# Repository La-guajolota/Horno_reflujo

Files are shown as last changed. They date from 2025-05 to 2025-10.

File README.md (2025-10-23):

<!-- @format -->

# 🔥 Homemade SMD Reflow Oven 🔥

<p align="center">
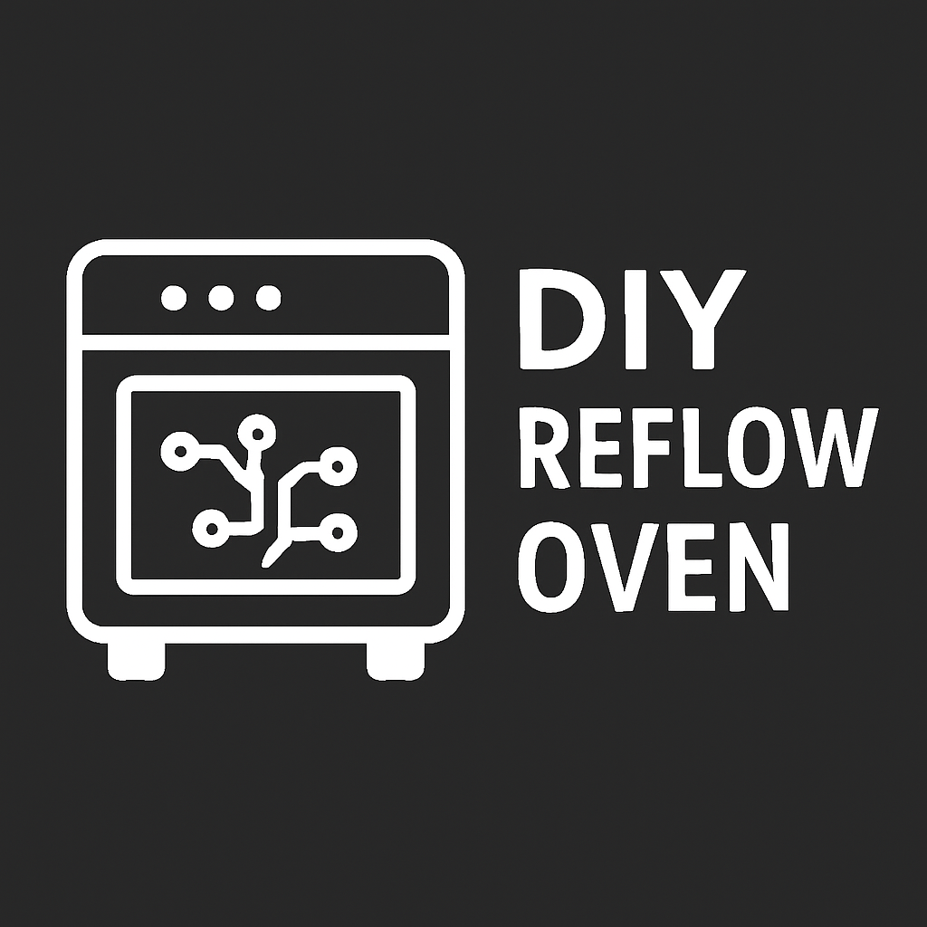
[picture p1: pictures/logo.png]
Project Logo
    
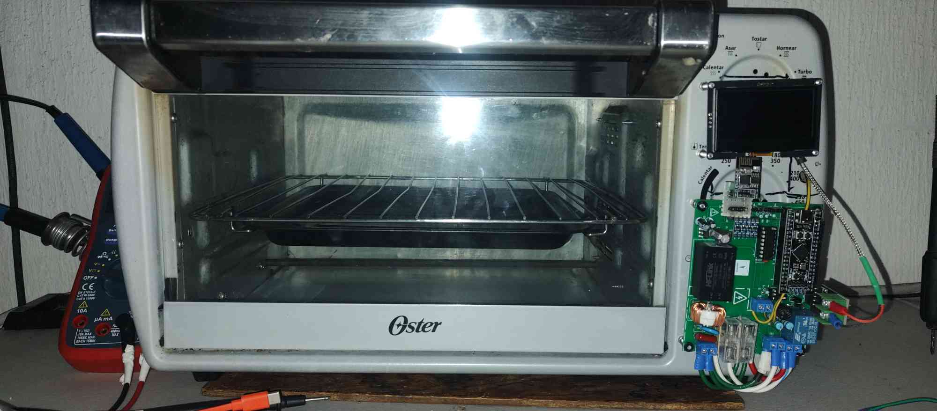
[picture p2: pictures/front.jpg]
Oven
    
</p>

## 📑 Table of Contents

- [Overview](#-overview)
- [Project Demo](#-project-demo)
- [Workflow](#-workflow)
- [Technical Challenges](#-technical-challenges)
- [Repository Structure](#-repository-structure)
- [Requirements & Dependencies](#-requirements--dependencies)
- [Installation & Usage](#-installation--usage)
- [To-Do List](#-to-do-list)
- [Possible Improvements](#-possible-improvements)
- [Safety Considerations](#-safety-considerations)
- [Contributing](#-contributing)
- [Reference Links](#-reference-links)
- [License](#-license)

---

## 📝 Overview

The **SMD Reflow Oven** is an open-source project designed for precise SMD soldering. It utilizes configurable thermal profiles managed by an **STM32F411** microcontroller and a web-based GUI hosted on an **ESP01-S**. Key features include real-time PID temperature control, smart power management, and robust safety systems.

> ✅ **Functional Demo**: All core features (PID control, temperature sensing, web GUI, and the reflow algorithm) are fully operational and ready for soldering SMD components.
> 🚧 **Active Development**: Both the firmware and hardware are under continuous improvement.

---

## 📹 Project Demo

See the oven in action! This video demonstrates its current functionality and soldering capabilities.

<p align="center">
<a href="https://youtu.be/XSk6v5LdElc?si=d4BS0npnXu5F3Sj0" target="_blank">
<b>Watch a video demonstration of the oven in action</b>
</a>
</p>

---

## 🔄 Workflow

<details>
<summary><b>Step-by-step SMD soldering process</b></summary>

### 1. 📋 PCB Preparation

- Apply solder paste evenly using a stencil.
- Carefully place the SMD components onto the pasted pads.

<p align="center">
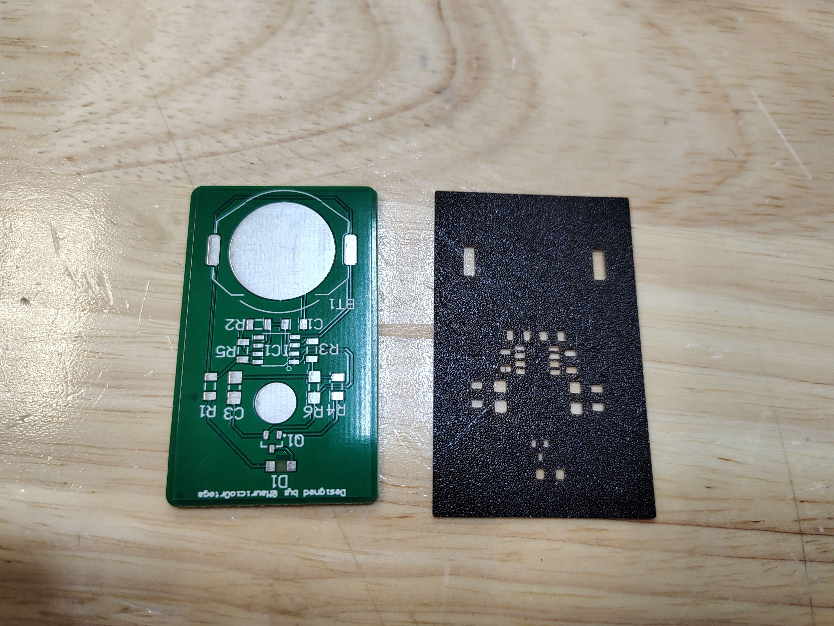
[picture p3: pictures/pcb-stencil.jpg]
PCB Preparation Example

</p>

### 2. ⚙️ Oven Setup

- Power the oven (120V AC).
- Select the appropriate thermal profile for your solder type via the web GUI.
- Verify that all safety systems are active.

### 3. 🔥 Soldering Process

- Place the prepared PCB inside the oven chamber.
- Close the door securely and start the process from the interface.
- Monitor the temperature curve in real-time to ensure it follows the selected profile.

<p align="center">
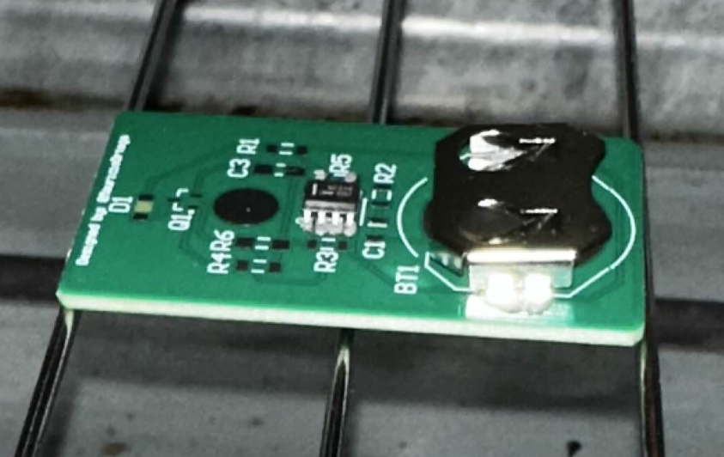
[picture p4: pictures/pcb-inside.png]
PCB Inside Oven

</p>

### 4. 🔍 Final Inspection

- Wait for the **Cooldown** phase to complete before opening the door.
- Allow the PCB to cool completely before handling.
- Inspect the solder joints with a magnifier or microscope for any defects.
- Perform electrical tests to check for shorts or open circuits.

<p align="center">
<a href="https://youtube.com/shorts/ztY0c23UdZQ?si=FxfqCBQ48sNtS6zn" target="_blank">
📺 Watch the final results on YouTube
</a>
</p>
</details>

---

## 🎯 Technical Challenges

| Challenge | Solution Approach |
| :--- | :--- |
| **Temperature Control** | Ensure uniform heat distribution, implement adaptable thermal curves, and design profiles to prevent component microcracks. |
| **Risk Management** | Implement automatic overheating detection and shutoff, along with a system for filtering potentially toxic vapors. |
| **Operational Precision** | Calibrate sensors accurately and synchronize heating/cooling stages for reliable and repeatable results. |

---

## 📂 Repository Structure

The **Serial Peripheral Interface (SPI)** is crucial in this project for fast communication between the STM32 microcontroller and peripherals like the **MAX6675 thermocouple sensors**, ensuring precise, real-time temperature readings for the PID control loop.

```
.
├── Firmware/                   # Firmware for all microcontrollers
│   ├── esp01/                  # ESP-01S firmware and related tools
│   ├── nextionGUI/             # Nextion HMI screen GUI files
│   └── stm32f411/              # STM32F411 firmware and related tools
├── Hardware/                   # Hardware design files (schematics, PCB)
│   ├── horno_no_modificado/  # Original, unmodified oven schematics
│   └── horno_reflujo/        # Custom reflow oven hardware
├── pictures/                   # Project images and photos
├── .gitignore                  # Git ignore file
├── LICENSE                     # Project license
└── README.md                   # This README file
```

---

## 📦 Requirements & Dependencies

### Software

- **PlatformIO**: Recommended for firmware development.
- **Python 3.x**: For data analysis and utility scripts.
- **KiCad**: For viewing and editing hardware schematics and PCB layouts.
- **STM32CubeIDE**: Optional, for STM32-specific development.

### Hardware

- Refer to the **Bill of Materials (BOM)** located in the `Hardware/horno_reflujo/` directory for a complete list of components.

---

## 🛠️ Installation & Usage

1.  **Clone the Repository:**
    ```bash
    git clone https://github.com/La-guajolota/Horno_reflujo.git
    cd Horno_reflujo
    ```
2.  **Setup Firmware:**
    - Open the `Firmware/` and `stm32f411/` directories in PlatformIO.
    - Follow the specific setup instructions within each folder to compile and upload the firmware.
3.  **Assemble Hardware:**
    - Use the schematics and PCB files in the `Hardware/` directory as a guide.
    - Solder and assemble all components according to the BOM.
4.  **Calibrate & Test:**
    - Before the first use, perform temperature sensor calibration.
    - Test all safety systems to ensure they are functioning correctly.

---

## 📋 To-Do List

### High Priority

- [ ] Complete the documentation for hardware assembly.
- [ ] Implement a physical emergency stop button.
- [ ] Create a detailed guide for sensor calibration procedures.
- [ ] Add unit tests for critical firmware functions.

### Medium Priority

- [ ] Develop a mobile-friendly interface or a dedicated app.
- [ ] Add data logging and analysis features to track performance.
- [ ] Create 3D printable designs for the enclosure.

### Low Priority

- [ ] Integrate with PCB design software for profile suggestions.
- [ ] Add cloud connectivity for remote monitoring.

---

## 🚀 Possible Improvements

### Firmware Enhancements

- **Advanced PID Control**: Implement auto-tuning algorithms and adaptive control for even greater precision.
- **Enhanced Safety**: Add redundant sensors and fail-safe mechanisms.
- **Intuitive UI**: Improve the user interface with a touchscreen, OLED display, or rotary encoder.
- **IoT Integration**: Allow for remote monitoring and control over the internet.
- **Ventilation Control**: Develop an automated system to manage toxic vapor extraction.

### Hardware Upgrades

- **Improved Insulation**: Enhance thermal efficiency and user safety.
- **High-Accuracy Sensors**: Upgrade to more precise temperature sensors.
- **Modular Design**: Create a modular system to support different oven sizes.
- **Power Efficiency**: Optimize heating element control to reduce energy consumption.
- **Electrical Isolation**: Improve electrical isolation between high-voltage and low-voltage circuits.

---

## ⚠️ Safety Considerations

- ⚡ **High Voltage**: This project involves **120V AC**. Exercise extreme caution and ensure all connections are properly insulated.
- 🌡️ **High Temperatures**: The oven reaches temperatures capable of causing severe burns. Use protective equipment.
- 💨 **Ventilation**: Solder paste fumes can be toxic. Operate the oven in a well-ventilated area.
- 🔧 **Grounding**: Ensure the oven chassis is properly grounded to prevent electrical shock.
- 📏 **Calibration**: Regularly calibrate temperature sensors to maintain accuracy and prevent overheating.

---

## 🤝 Contributing

Contributions are welcome\! If you'd like to help improve this project, please follow these steps:

1.  **Fork the repository.**
2.  Create a new branch: `git checkout -b feature/your-amazing-feature`
3.  Make your changes and commit them: `git commit -m 'Add your amazing feature'`
4.  Push to your branch: `git push origin feature/your-amazing-feature`
5.  **Open a Pull Request** and describe the changes you've made.

Please report any bugs or suggest features by opening an issue on GitHub.

---

## 🔗 Reference Links

- [Nextion HMI Displays](https://nextion.tech/) – Official site for Nextion touchscreen displays.
- [gerber_to_scad (GitHub)](https://github.com/kirberich/gerber_to_scad) – Tool for generating 3D stencils from Gerber files.
- [SMD Soldering Guidelines](https://www.surfacemountprocess.com/reflow-soldering-process.html) – Comprehensive guide to the reflow soldering process.
- [Reflow Soldering Profiles (SMTA)](https://www.smta.org/) – Industry resources and recommended thermal profiles.
- [DIY Reflow Oven on Instructables](https://www.instructables.com/DIY-REFLOW-OVEN/) – Step-by-step guide for building a reflow oven with open-source firmware.
- [Hack Your Toaster Oven to Become a Thermocouple Measurement System (All About Circuits)](https://www.allaboutcircuits.com/projects/hack-your-toaster-oven-to-become-a-thermocouple-measurement-system/) – Reference for thermocouple integration and reflow process insights.
- [Better SPI Bus Design in 3 Steps (DorkbotPDX)](https://dorkbotpdx.org/blog/paul/better_spi_bus_design_in_3_steps/) – Key considerations for reliable MAX6675 sensor communication.

---

## 📄 License

This project is licensed under the **MIT License**. See the [LICENSE](https://www.google.com/search?q=LICENSE) file for more details. This means you are free to use, modify, and distribute the project, provided you include the original copyright and license notice.

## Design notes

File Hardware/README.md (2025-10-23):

# 🛠️ Hardware 🛠️

<p align="center">
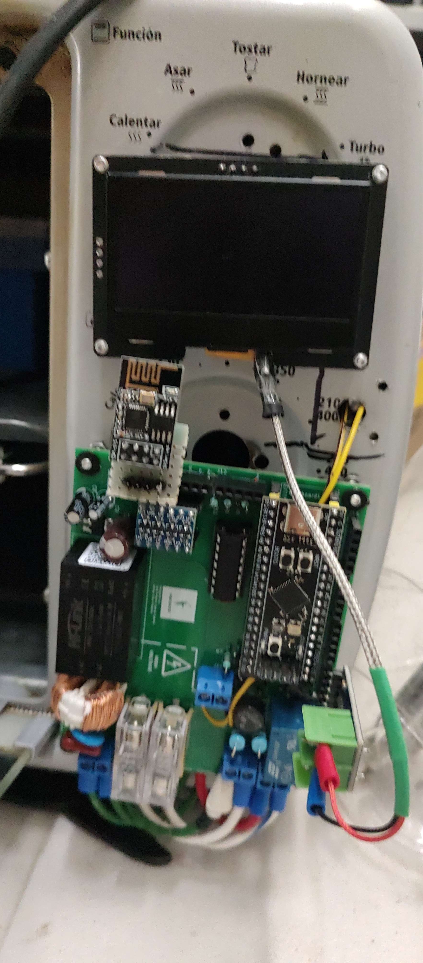
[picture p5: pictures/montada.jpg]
Hardware Banner
  
</p>

This directory contains all the hardware design files for the **SMD Reflow Oven** project. This includes KiCad project files, schematics, PCB layouts, and other related resources.

---

## 📂 Folder Structure

- **horno_no_modificado/**: Contains the original, unmodified schematic files for the oven.
- **horno_reflujo/**: The main KiCad project for the custom reflow oven hardware. This includes:
  -  schematics (`.kicad_sch`)
  - PCB layout (`.kicad_pcb`)
  - Bill of Materials (BOM)
  - Production files for manufacturing.
- **imagenes/**: Reference images and diagrams.

---

## 🚀 Getting Started

To work with the hardware files, you will need:

- **KiCad**: To open and edit the schematic and PCB layout files.

Each subdirectory contains a more detailed `README.md` file with specific instructions on how to use its contents.

---

## 📝 PCB Design Notes & Improvements

While the current electronics are functional, several improvements have been identified for future revisions of the PCB:

- **Component Sizing**: Migrate all through-hole (THT) components to surface-mount (SMD) to reduce board size.
- **Simplify Temperature Sensing**: The current design uses four thermocouples, but one is sufficient. Reducing to a single thermocouple will simplify the circuit and free up microcontroller pins.
- **Isolate Mounting Holes**: The mounting holes are currently connected to the ground plane, which is not ideal. They should be isolated to prevent potential short circuits.
- **Upgrade Connectors**: The external connectors are undersized for the required current. They should be replaced with larger terminals.

---

## 🏠 Enclosure Design Notes & Improvements

The 3D model for the enclosure was designed in Autodesk Inventor. The following improvements have been identified:

- **Reduce Size**: By optimizing the PCB, the enclosure can be made smaller.
- **Improve Closure Mechanism**: The current screw-based closure can be replaced with a more practical solution like snap-fit tabs.
- **Add Accessibility**: Add openings for ventilation and easier access to connectors.

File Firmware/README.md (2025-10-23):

# 펌웨어 | Firmware 펌웨어

<p align="center">
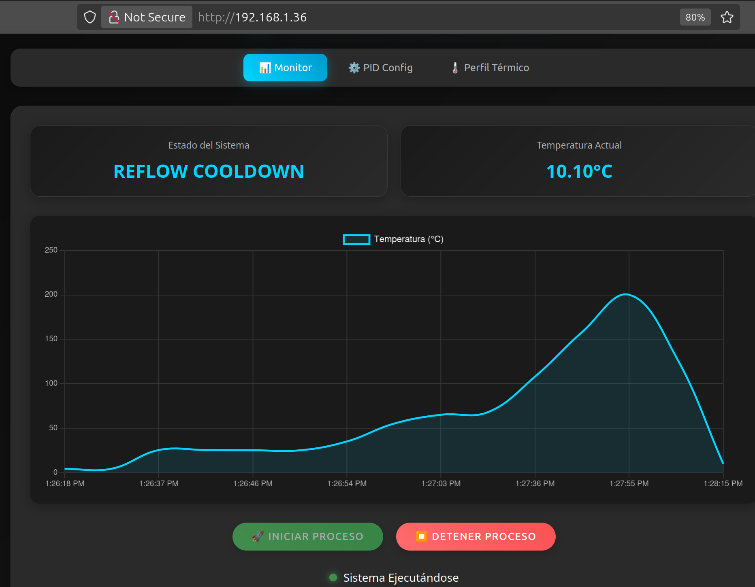
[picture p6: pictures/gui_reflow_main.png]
Firmware Banner
  
</p>

This directory contains all the firmware for the microcontrollers used in the **SMD Reflow Oven** project.

---

## 📂 Subdirectories

Here's a breakdown of what you'll find in each subfolder:

- ###  esp01/
  This folder holds the firmware for the **ESP-01S** module, which is responsible for hosting the web-based GUI. It includes the PlatformIO project and related tools for debugging and data analysis.

- ### nextionGUI/
  Contains the files for the **Nextion HMI** touchscreen display. This includes the `.HMI` file that defines the graphical user interface and custom fonts.

- ### stm32f411/
  This is where the main control firmware for the **STM32F411** microcontroller is located. This firmware manages the PID temperature control, thermal profiles, and all core functionalities of the oven. It also includes design files for a Kalman filter used for temperature sensing.

---

## 🚀 Getting Started

To work with the firmware in this directory, you will need:

- **PlatformIO** for the `esp01` and `stm32f411` projects.
- **Nextion Editor** for the `nextionGUI` files.
- **Python 3.x** for the utility scripts.

Each subdirectory contains a more detailed `README.md` file with specific instructions on how to use its contents.

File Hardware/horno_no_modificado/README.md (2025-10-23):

#  unmodified oven

This directory contains the schematic files for the original, unmodified oven. These files are provided for reference.

---

## 📂 Files

- **esquema_horno_no_modificado.kicad_pro**: The KiCad project file.
- **esquema_horno_no_modificado.kicad_sch**: The KiCad schematic file.

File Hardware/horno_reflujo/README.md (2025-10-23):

# 🔥 Custom Reflow Oven Hardware 🔥

This directory contains the main **KiCad project** for the custom reflow oven hardware.

---

## 📂 Files & Folders

- **horno_reflujo.kicad_pro**: The main KiCad project file.
- **horno_reflujo.kicad_sch**: The schematic file.
- **horno_reflujo.kicad_pcb**: The PCB layout file.
- **bom/**: Contains the Bill of Materials (BOM) for the project.
- **production/**: Contains the fabrication output files (Gerbers, drill files, etc.) for manufacturing the PCB.
- **horno_reflujo-backups/**: Automatic backups of the project files.

---

## 🚀 How to Use

1. **Open in KiCad**: Open the `horno_reflujo.kicad_pro` file in KiCad.
2. **View Schematic & PCB**: You can view and edit the schematic and PCB layout.
3. **Generate Fabrication Files**: Use the PCB editor to generate the fabrication files, which will be located in the `production/` directory.

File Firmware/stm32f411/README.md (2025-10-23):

# 🧠 STM32F411 Firmware 🧠

<p align="center">
  STM32F411 Banner
</p>

Welcome to the **STM32F411** section of the Reflow Oven Firmware project! This directory contains the core firmware that controls the reflow oven, running on an STM32F411 microcontroller.

---

## 📂 Folder Structure

```
stm32f411/
├── Kalman_filter_desing/   # MATLAB/Octave scripts for sensor filtering and analysis
└── reflow_oven/            # Main STM32 firmware (STM32CubeIDE project)
```

---

## 🛠️ Components

### 1. **Kalman_filter_desing/**

- **Purpose:**  
  Contains MATLAB/Octave scripts used to design and analyze a Kalman filter for reducing noise from the temperature sensors.
- **Usage:**  
  The filter coefficients generated from these scripts can be ported to the C firmware to improve temperature reading accuracy.

### 2. **reflow_oven/**

- **Purpose:**  
  The main STM32CubeIDE project for the reflow oven. This is the heart of the oven's control system.
- **Features:**
  - 🔥 **PID Control**: Precise temperature regulation using a PID controller.
  - 🔄 **State Machine**: Manages the different stages of the reflow process (preheat, soak, reflow, cooldown).
  - 🌡️ **Sensor Interface**: Reads data from thermocouple sensors (e.g., MAX6675).
  - 🖥️ **UI Backend**: Provides data to the user interface (web GUI or Nextion display).

---

## 🚀 Getting Started

1. **Open in STM32CubeIDE**: Open the `reflow_oven/` directory as a project in STM32CubeIDE.
2. **Configure Peripherals**: Use the `.ioc` file (STM32CubeMX) to view and modify the microcontroller's peripheral configurations.
3. **Build & Flash**: Build the project and flash the firmware to your STM32F411 board.
4. **Test & Debug**: Use a serial debugger to monitor the oven's status and troubleshoot any issues.

---

## ✅ To-Do List

- [ ] Refactor the state machine for better modularity.
- [ ] Implement EEPROM/Flash storage for user-defined reflow profiles.
- [ ] Add more advanced safety features (e.g., door open detection).
- [ ] Integrate a PID auto-tuning algorithm.
- [ ] Add unit tests for critical modules.

---

## 🤝 Contributing

Pull requests and suggestions are welcome! Please open an issue for bugs or feature requests.

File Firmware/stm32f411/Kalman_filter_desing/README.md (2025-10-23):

# 📈 Kalman Filter Design 📈

This directory contains scripts for designing and analyzing a **Kalman filter** to reduce noise from the temperature sensors in the reflow oven.

---

## 📂 Files

- **FOPDT.m**: A MATLAB/Octave script for First-Order Plus Dead Time (FOPDT) modeling of the system.
- **Kalmanfilter0.py**: A Python script for designing and simulating the Kalman filter.
- **octave_analysis.m**: A MATLAB/Octave script for analyzing the filter's performance.
- **resultado_filtro_kalman.png**: An image showing the results of the Kalman filter analysis.

---

## 🚀 How to Use

1. **Run Scripts**: Use MATLAB, Octave, or Python to run the scripts and analyze the filter's behavior.
2. **Port to C**: The resulting filter coefficients can be ported to the main STM32 firmware to improve the accuracy of the temperature readings.

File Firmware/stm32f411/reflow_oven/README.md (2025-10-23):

# 🔥 Reflow Oven Firmware 🔥

This directory contains the main **STM32CubeIDE project** for the reflow oven. This firmware is the core of the oven's control system.

---

## 📂 Project Structure

- **Core/**: Contains the main application source code, including `main.c`, the state machine, and drivers for peripherals.
- **Drivers/**: STM32 HAL drivers and CMSIS.
- **.ioc**: The STM32CubeMX configuration file. You can open this file to view and edit the microcontroller's peripheral settings.
- **.cproject** and **.project**: Eclipse project files for STM32CubeIDE.

---

## 🚀 How to Use

1. **Open in STM32CubeIDE**: Import this directory as a project in the STM32CubeIDE.
2. **Configure Peripherals**: Double-click the `.ioc` file to open the STM32CubeMX perspective and configure the microcontroller's peripherals.
3. **Build & Flash**: Build the project and flash the firmware to your STM32F411 board.
4. **Debug**: Use the debugging tools in STM32CubeIDE to test and debug the firmware.

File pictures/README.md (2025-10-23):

# 🖼️ Pictures 🖼️

This directory contains various pictures of the **SMD Reflow Oven** project, including photos of the hardware and screenshots of the GUI.

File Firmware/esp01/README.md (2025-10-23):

# 📶 ESP01 Firmware & Tools 📶

<p align="center">
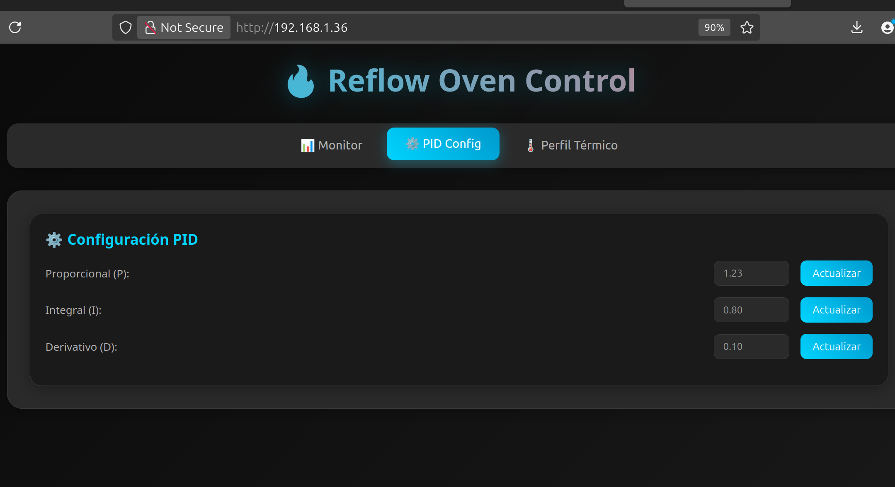
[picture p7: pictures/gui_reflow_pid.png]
ESP01 Banner
  
</p>

Welcome to the **ESP01** section of the Reflow Oven Firmware project! This folder contains everything needed to enable wireless control, monitoring, and data analysis for your reflow oven using the ESP8266 microcontroller.

---

## 📂 Folder Structure

```
esp01/
├── esp01_webGUI/      # ESP8266 Web GUI firmware (PlatformIO project)
├── serial_debug/      # Python scripts for serial debugging and communication
└── web_scrap/         # Data analysis and web client scripts
```

---

## 🛠️ Components

### 1. **esp01_webGUI/**

- **Purpose:**  
  ESP8266 firmware for a web-based GUI to control and monitor the oven remotely.
- **Tech:**  
  PlatformIO, Arduino framework, HTML/CSS/JS for the web interface.
- **Features:**
  - 📡 Real-time temperature monitoring
  - 🎛️ Oven profile selection
  - 🕹️ Manual and automatic control modes
  - 🌐 WiFi configuration

### 2. **serial_debug/**

- **Purpose:**  
  Python utilities for serial communication and debugging.
- **Features:**
  - 📝 Log oven data
  - 📤 Send commands via USB serial
  - 🐛 Debug and test firmware responses

### 3. **web_scrap/**

- **Purpose:**  
  Scripts for data analysis, regression, and client-side logging.
- **Features:**
  - 📈 Analyze thermal profiles
  - 📄 Generate reports
  - 📊 Excel integration for advanced data visualization

---

## 🚀 Getting Started

1. **Web GUI Firmware**

   - Open `esp01_webGUI/` in PlatformIO.
   - Edit `configs.hpp` to set your WiFi credentials.
   - Build and upload to your ESP01 module.

2. **Serial Debugging**

   - Install Python 3 and required packages (`pip install pyserial`).
   - Run scripts in `serial_debug/` to communicate with the oven.

3. **Data Analysis**
   - Use scripts in `web_scrap/` for regression and thermal profile analysis.
   - Open Excel files for advanced data visualization.

---

## ✅ To-Do List

- [ ] Add OTA (Over-the-Air) firmware update support
- [ ] Improve mobile responsiveness of the web GUI
- [ ] Implement user authentication for web access
- [ ] Add MQTT integration for IoT platforms
- [ ] Enhance logging and error reporting in Python scripts
- [ ] Create example thermal profiles for testing

---

## 🤝 Contributing

Pull requests and suggestions are welcome! Please open an issue for bugs or feature requests.

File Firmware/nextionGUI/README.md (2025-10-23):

# 🖼️ Nextion GUI 🖼️

<p align="center">
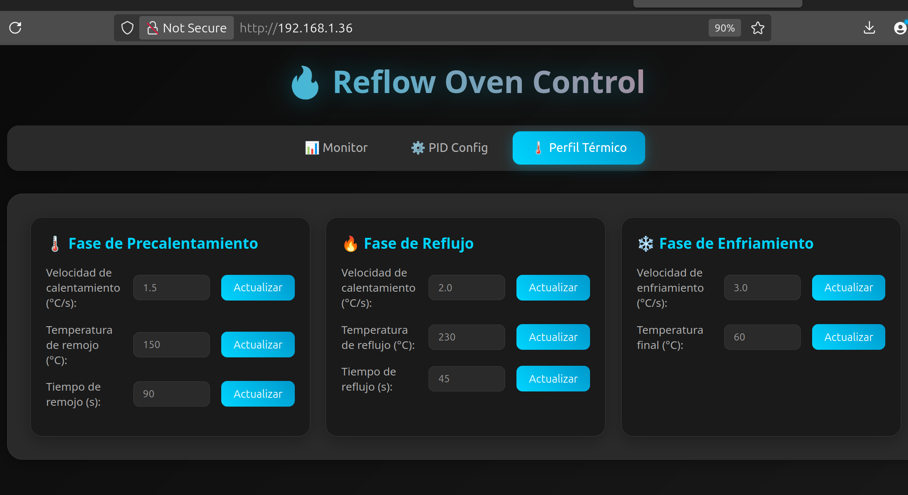
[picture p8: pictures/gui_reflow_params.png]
Nextion GUI Banner
  
</p>

This folder contains the graphical user interface (GUI) project for the **Nextion HMI touchscreen display**.

---

## 📂 Contents

- **Reflow.HMI**: The main project file for the Nextion Editor.
- **fuentes/**: Custom fonts used in the GUI.
- **imagenes/**: Image assets for the interface.

---

## ✨ Features

- 🌡️ Real-time temperature display
- 📈 Oven profile selection
- 🔘 Manual and automatic control buttons
- ⚠️ Error and status notifications

---

## 🚀 Getting Started

1. **Open in Nextion Editor**: Open the `Reflow.HMI` file in the [Nextion Editor](https://nextion.tech/nextion-editor/).
2. **Customize**: Edit the screens, UI elements, and assets as needed.
3. **Compile & Upload**: Compile the project to generate a `.tft` file and upload it to your Nextion display.

---

## 📝 Note

The Nextion GUI was **not included in the final implementation** of the reflow oven. However, the files are available here if you wish to use a Nextion touchscreen display. Communication with the main MCU is done via UART, and designing the interface with the Nextion Editor is a fast and easy way to create a touch-enabled GUI.

For a demonstration of the Nextion GUI in action, watch this [YouTube video](https://youtube.com/shorts/_j2yINKcmlk?si=kRPrA2X6i5ZX8LdD).

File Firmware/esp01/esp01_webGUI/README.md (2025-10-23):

# 🌐 ESP01 Web GUI 🌐

<p align="center">
  Web GUI Banner
</p>

This directory contains the PlatformIO project for the **ESP-01S web-based GUI**. This firmware allows you to control and monitor the reflow oven wirelessly from any web browser.

---

## 📂 Project Structure

- **src/**: Contains the main source code (`main.cpp`).
- **include/**: Header files.
- **lib/**: Project-specific libraries.
- **platformio.ini**: PlatformIO project configuration file.

---

## 🚀 How to Use

1. **Open in PlatformIO**: Open this directory as a project in the PlatformIO IDE.
2. **Configure WiFi**: Edit the `src/main.cpp` file to set your WiFi credentials (SSID and password).
3. **Build & Upload**: Build the project and upload the firmware to your ESP-01S module.
4. **Connect**: Once uploaded, the ESP-01S will connect to your WiFi network and host the web server. You can access the GUI by navigating to the IP address of the ESP-01S in your web browser.

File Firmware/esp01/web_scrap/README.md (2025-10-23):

# 📊 Web Scraping & Data Analysis 📊

This directory contains Python scripts and other files for web scraping and data analysis related to the reflow oven project.

---

## 📂 Files

- **web_client.py**: A Python script that acts as a web client to interact with the oven's web interface. It can be used to automate testing and data logging.
- **fopdt.py**: A script for First-Order Plus Dead Time (FOPDT) modeling, used for analyzing the thermal dynamics of the oven.
- **regresion_horno.xlsx** and **regresion_horno2.xlsx**: Excel files containing data for regression analysis of the oven's temperature profiles.
- **horno_client.log**: A log file generated by the `web_client.py` script.

---

## 🚀 How to Use

1. **Install Dependencies**: Make sure you have Python 3 and any required libraries installed (e.g., `pandas`, `openpyxl`, `requests`).
2. **Run Scripts**: Use the Python scripts to perform data analysis or interact with the web client.
   ```bash
   python web_client.py
   ```

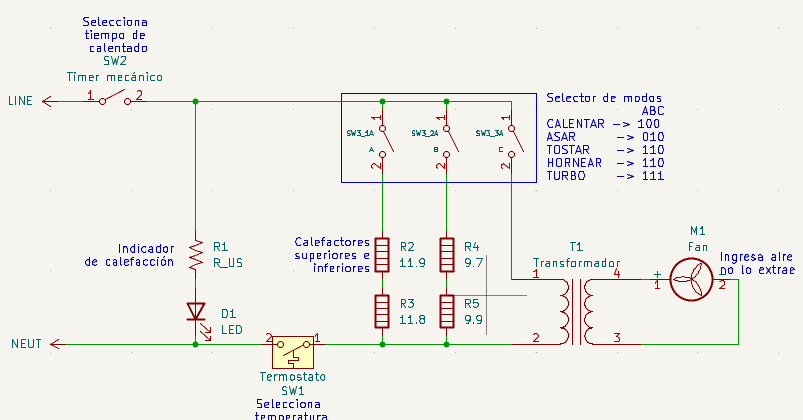
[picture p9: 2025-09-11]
Hardware/imagenes/original_oven.png

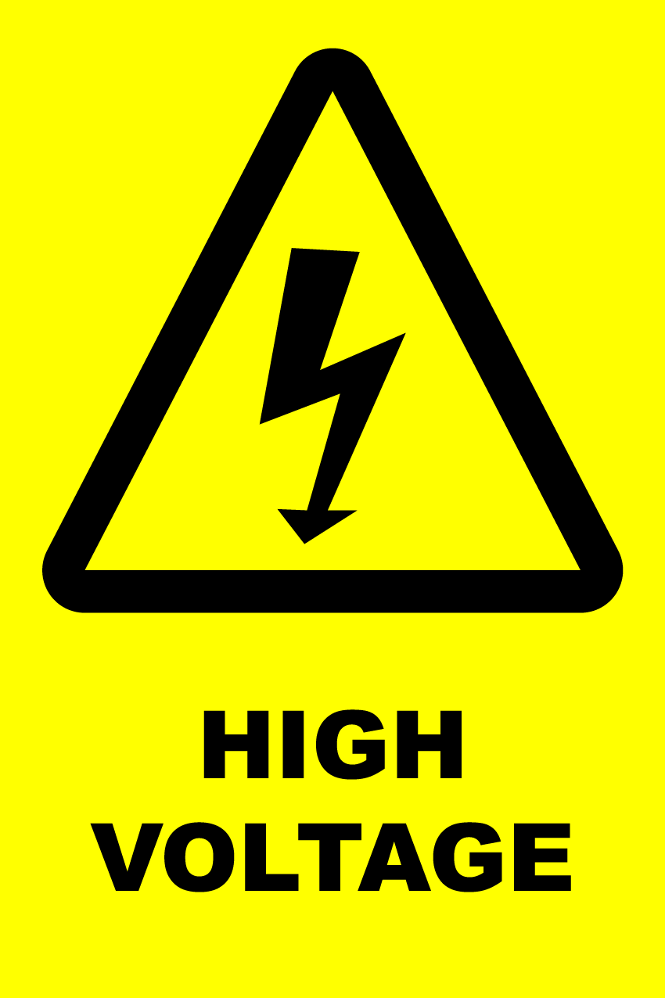
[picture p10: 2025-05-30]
Hardware/imagenes/Caution-High-Voltage-300x450.png

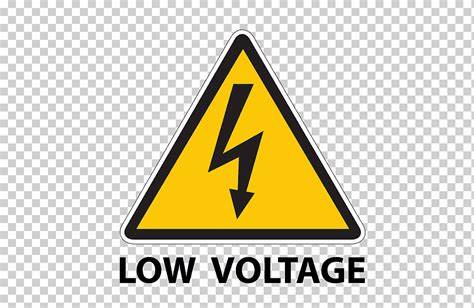
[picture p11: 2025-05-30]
Hardware/imagenes/OIP.jpeg

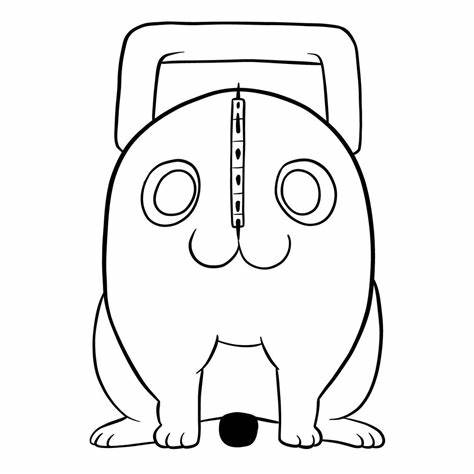
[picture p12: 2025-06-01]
Hardware/imagenes/pochi.jpeg

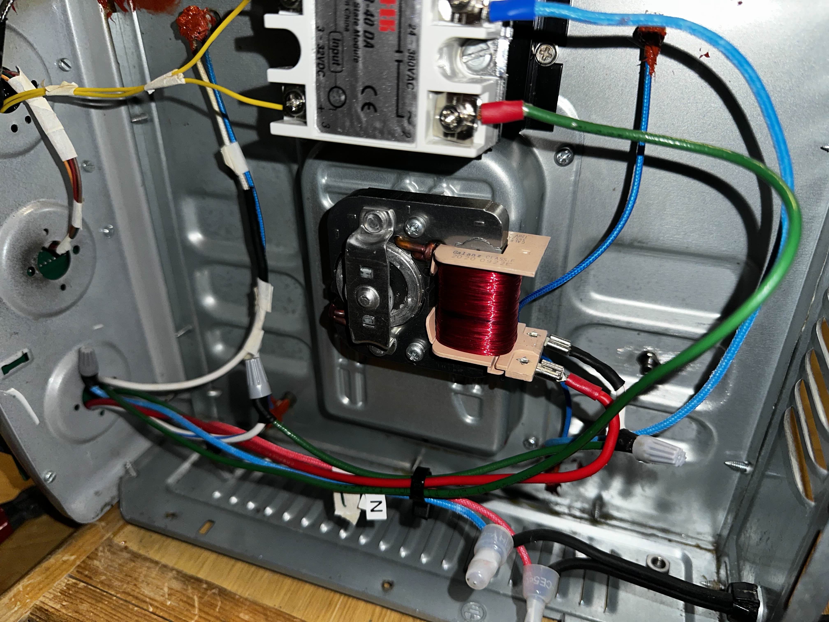
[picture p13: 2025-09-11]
pictures/inside.jpg

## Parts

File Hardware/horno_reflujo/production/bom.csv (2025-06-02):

Designator | Footprint | Quantity | Value | LCSC Part #
C1 | CP_Radial_D5.0mm_P2.50mm | 1 | 220uf
C2 | C_Disc_D5.1mm_W3.2mm_P5.00mm | 1 | 0.1uF/275Vac
C5 | C_Disc_D5.1mm_W3.2mm_P5.00mm | 1 | 100nf
C8 | CP_Radial_D5.0mm_P2.50mm | 1 | 10uf
C9 | CP_Radial_D5.0mm_P2.50mm | 1 | 1uf
D1 | Diode_Bridge_Round_D9.0mm | 1 | 2W02G
D3 | D_A-405_P10.16mm_Horizontal | 1 | 1N4001
DEV_BOARD1 | Maple_Mini | 1 | Black_pill_stm32f411
F1 | Fuseholder_Cylinder-5x20mm_Schurter_0031_8201_Horizontal_Open | 1 | 0.5A
F2 | Fuseholder_Cylinder-5x20mm_Schurter_0031_8201_Horizontal_Open | 1 | 15A
FL1 | Choke_Schaffner_RN102-04-14.0x14.0mm | 1 | Choke_10mH
J1, J2 | PinHeader_1x06_P2.54mm_Vertical | 2 | LevelShifter
J10 | TerminalBlock_bornier-2_P5.08mm | 1 | ssr1
J11 | TerminalBlock_bornier-2_P5.08mm | 1 | ssr2
J12 | PinHeader_1x05_P2.54mm_Vertical | 1 | encoder
J13 | PinHeader_1x05_P2.54mm_Vertical | 1 | Max6675_modulo2
J14 | PinHeader_1x05_P2.54mm_Vertical | 1 | Max6675_modulo3
J15 | PinHeader_1x05_P2.54mm_Vertical | 1 | Max6675_modulo4
J3 | PinHeader_1x04_P2.54mm_Vertical | 1 | Display Oled I2C
J4 | PinHeader_1x05_P2.54mm_Vertical | 1 | Max6675_modulo
J5 | PinHeader_1x04_P2.54mm_Vertical | 1 | ESP01
J6 | TerminalBlock_bornier-2_P5.08mm | 1 | Alimentación y zc
J7 | TerminalBlock_bornier-2_P5.08mm | 1 | Relevador a ventilador
K1 | Relay_SPDT_SANYOU_SRD_Series_Form_C | 1 | SANYOU_SRD_Form_C
OC1 | DIP-4_W10.16mm | 1 | PC817
PS1 | Converter_ACDC_Hi-Link_HLK-PMxx | 1 | HLK-PM01
Q1 | TO-92 | 1 | 2N2222A-TO92
R10 | R_Axial_DIN0207_L6.3mm_D2.5mm_P2.54mm_Vertical | 1 | 1K
R11, R7, R8, R9 | R_Axial_DIN0207_L6.3mm_D2.5mm_P2.54mm_Vertical | 4 | 10K
R5, R6 | R_Axial_DIN0411_L9.9mm_D3.6mm_P5.08mm_Vertical | 2 | 5k 1W
RV1 | RV_Disc_D7mm_W4.2mm_P5mm | 1 | 10D561K
U1 | SOT-223-3_TabPin2 | 1 | LD1117S33TR_SOT223
U2 | DIP-14_W7.62mm_Socket_LongPads | 1 | 74LS14

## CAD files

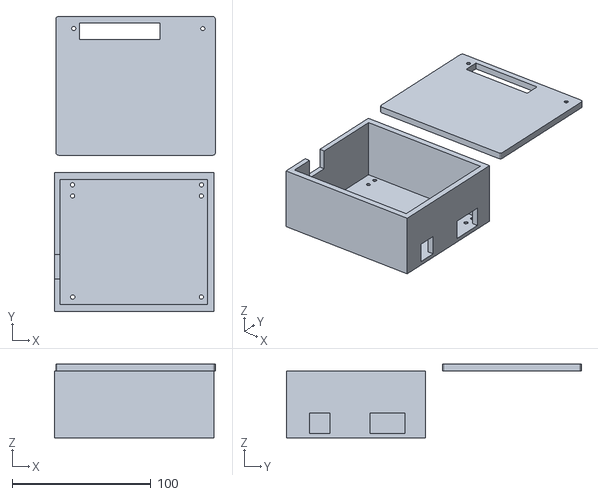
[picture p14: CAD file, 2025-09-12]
Hardware/horno_reflujo.stl
115.9 x 212.5 x 53.0

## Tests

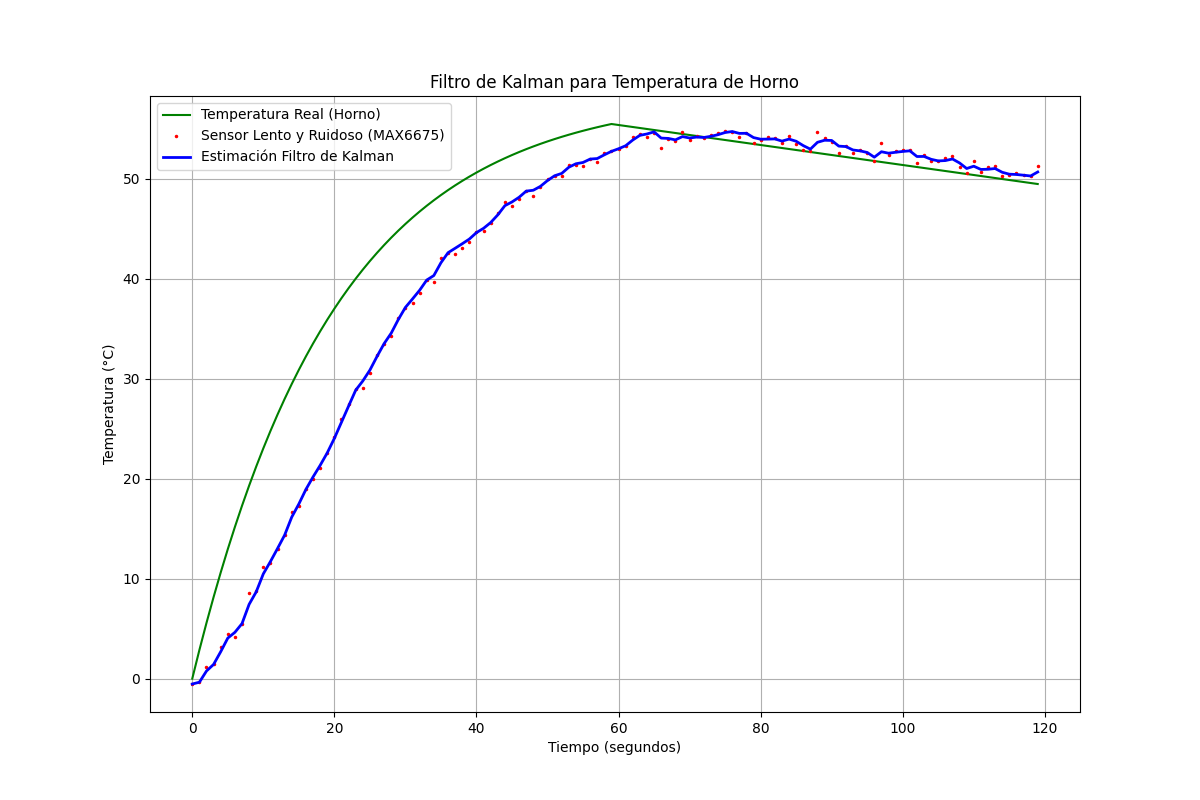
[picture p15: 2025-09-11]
Firmware/stm32f411/Kalman_filter_desing/resultado_filtro_kalman.png

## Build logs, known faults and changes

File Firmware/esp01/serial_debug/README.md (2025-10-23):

# 🐍 Serial Debug 🐍

This directory contains Python scripts for debugging the reflow oven's firmware via serial communication.

---

## 📂 Files

- **serialTest.py**: A script to test serial communication with the microcontroller. It sends commands and prints the responses.
- **serialUtils.py**: A collection of utility functions to handle serial data, such as parsing and formatting.

---

## 🚀 How to Use

1. **Install Dependencies**: Make sure you have Python 3 and the `pyserial` library installed:
   ```bash
   pip install pyserial
   ```
2. **Connect Hardware**: Connect the microcontroller to your computer via a USB-to-serial adapter.
3. **Run Scripts**: Run the `serialTest.py` script to start debugging:
   ```bash
   python serialTest.py
   ```

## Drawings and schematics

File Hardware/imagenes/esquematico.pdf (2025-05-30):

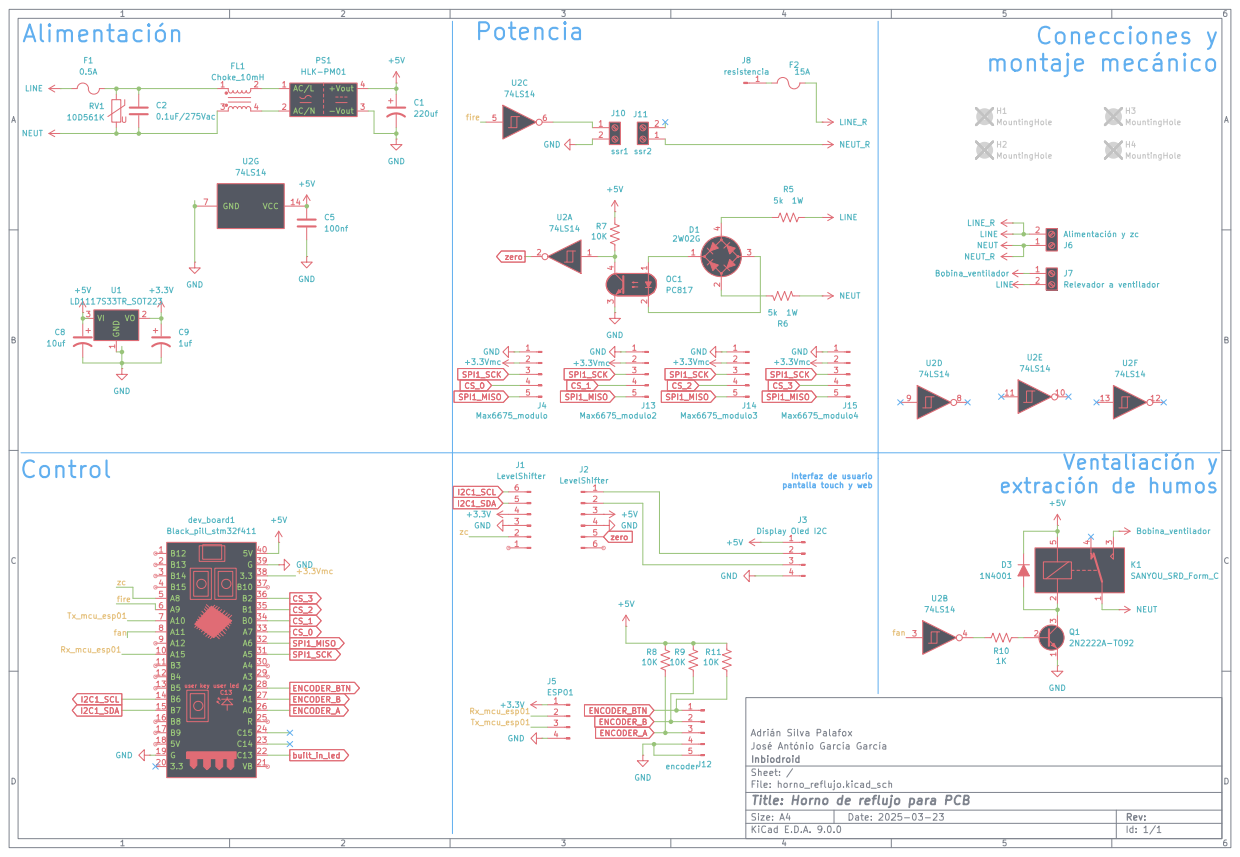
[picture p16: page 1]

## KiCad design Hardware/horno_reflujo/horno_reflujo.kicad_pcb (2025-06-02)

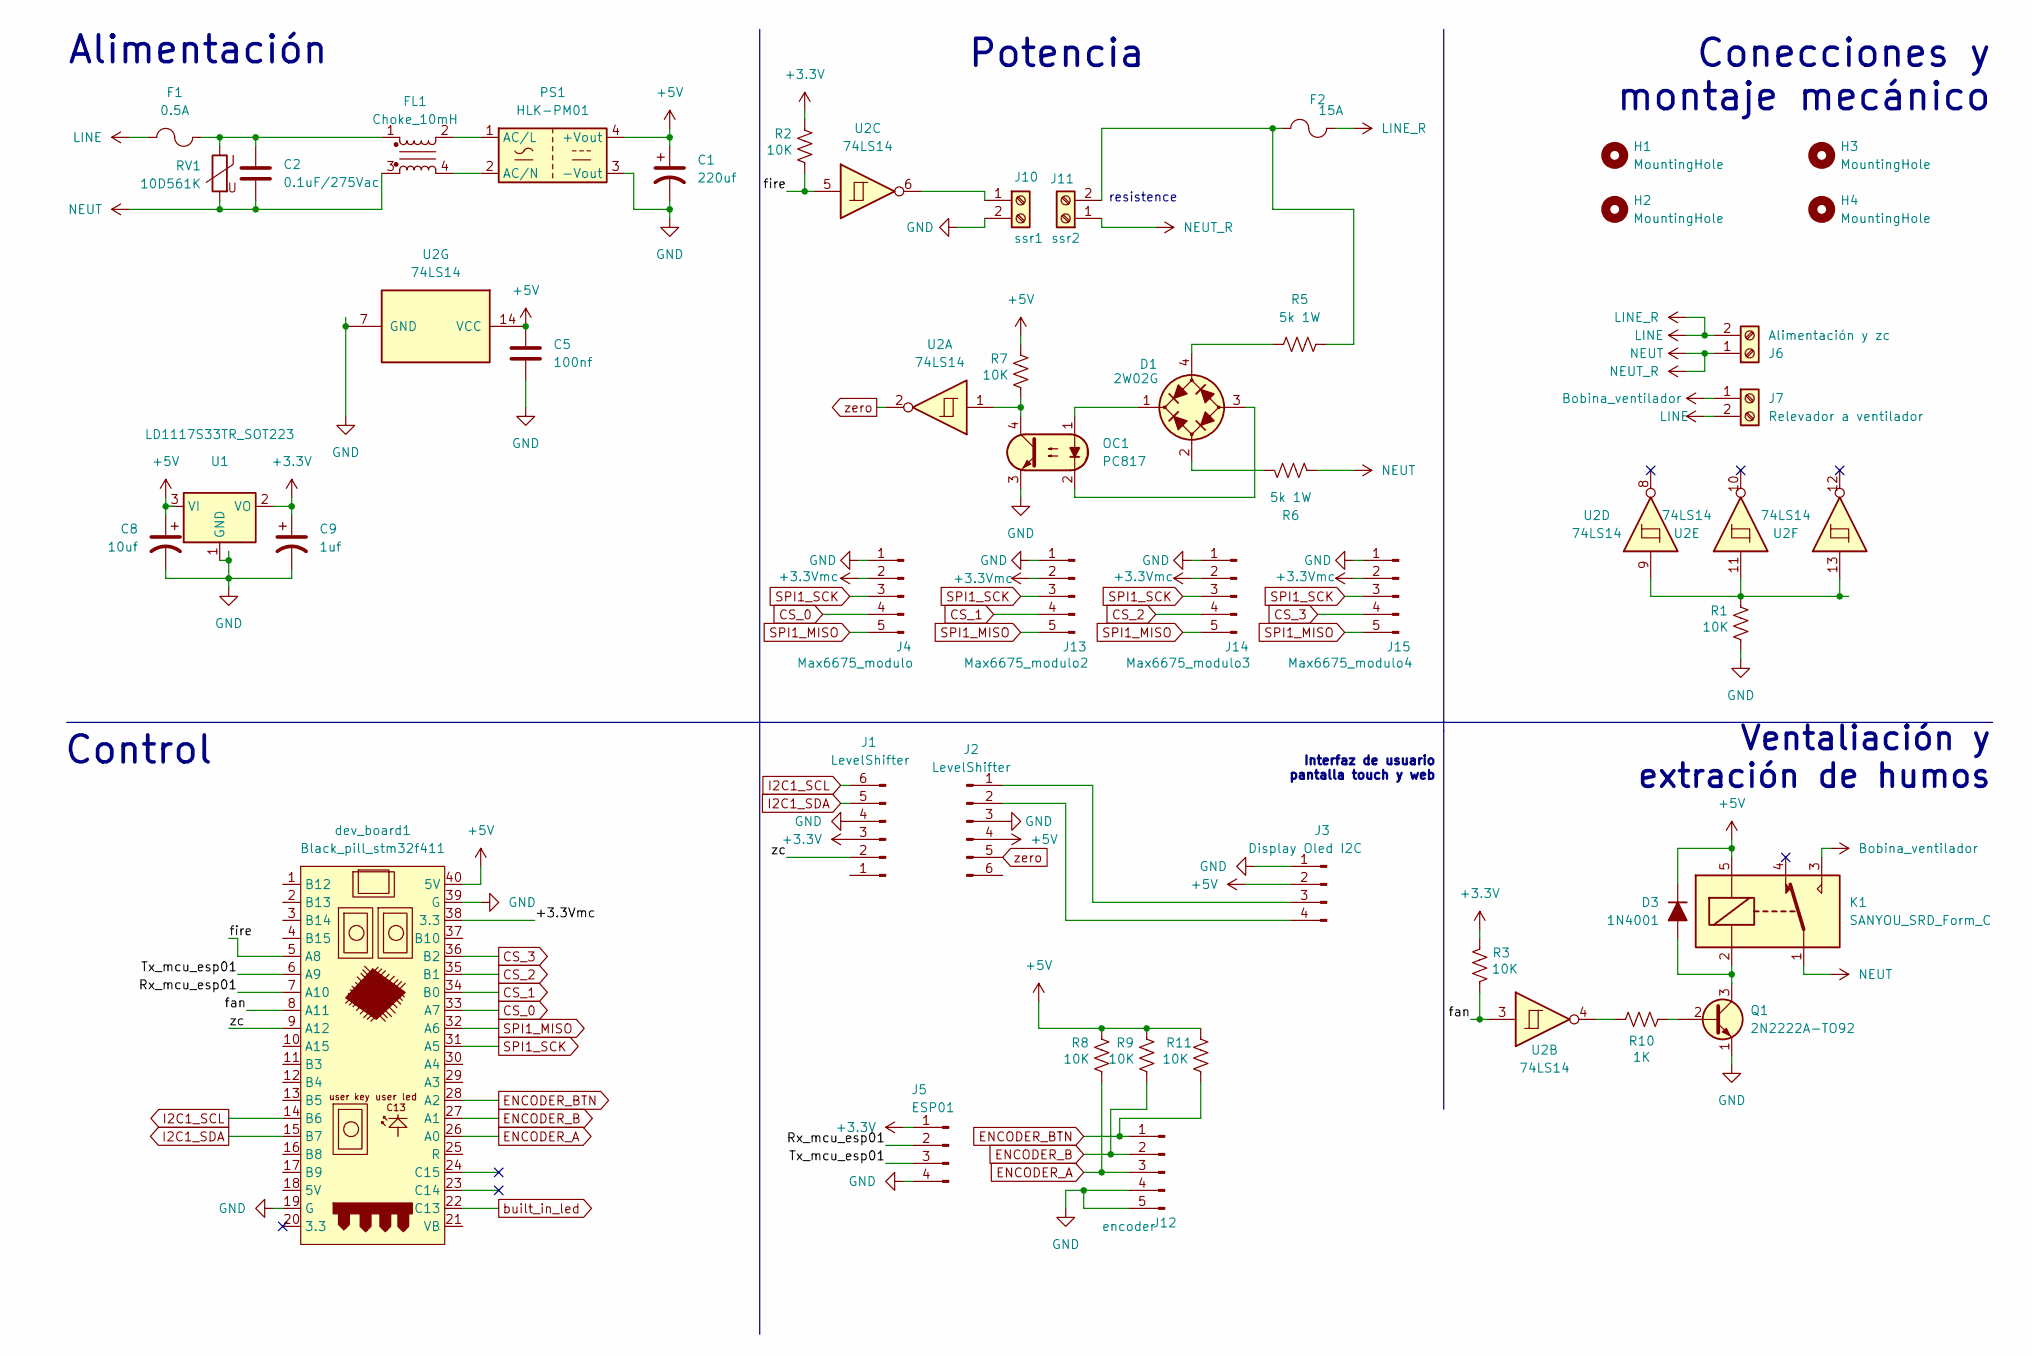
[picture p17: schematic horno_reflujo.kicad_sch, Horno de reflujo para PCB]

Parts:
C1: 220uf; CP_Radial_D5.0mm_P2.50mm
C2: 0.1uF/275Vac; C_Disc_D5.1mm_W3.2mm_P5.00mm
C5: 100nf; C_Disc_D5.1mm_W3.2mm_P5.00mm
C8: 10uf; CP_Radial_D5.0mm_P2.50mm
C9: 1uf; CP_Radial_D5.0mm_P2.50mm
D1: 2W02G; Diode_Bridge_Round_D9.0mm
D3: 1N4001; D_A-405_P10.16mm_Horizontal
F1: 0.5A; Fuseholder_Cylinder-5x20mm_Schurter_0031_8201_Horizontal_Op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
F2: 15A; Fuseholder_Cylinder-5x20mm_Schurter_0031_8201_Horizontal_Op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
FL1: Choke_10mH; Choke_Schaffner_RN102-04-14.0x14.0mm
H1, H2, H3, H4: MountingHole; MountingHole_3.2mm_M3_DIN965
J1, J2: LevelShifter; PinHeader_1x06_P2.54mm_Vertical
J3: Display Oled I2C; PinHeader_1x04_P2.54mm_Vertical
J4: Max6675_modulo; PinHeader_1x05_P2.54mm_Vertical
J5: ESP01; PinHeader_1x04_P2.54mm_Vertical
J6: Alimentación y zc; TerminalBlock_bornier-2_P5.08mm
J7: Relevador a ventilador; TerminalBlock_bornier-2_P5.08mm
J10: ssr1; TerminalBlock_bornier-2_P5.08mm
J11: ssr2; TerminalBlock_bornier-2_P5.08mm
J12: encoder; PinHeader_1x05_P2.54mm_Vertical
J13: Max6675_modulo2; PinHeader_1x05_P2.54mm_Vertical
J14: Max6675_modulo3; PinHeader_1x05_P2.54mm_Vertical
J15: Max6675_modulo4; PinHeader_1x05_P2.54mm_Vertical
K1: SANYOU_SRD_Form_C; Relay_SPDT_SANYOU_SRD_Series_Form_C
OC1: PC817; DIP-4_W10.16mm
PS1: HLK-PM01; Converter_ACDC_Hi-Link_HLK-PMxx
Q1: 2N2222A-TO92; TO-92
R1, R2, R3, R7, R8, R9, R11: 10K; R_Axial_DIN0207_L6.3mm_D2.5mm_P2.54mm_Vertical
R5, R6: 5k 1W; R_Axial_DIN0411_L9.9mm_D3.6mm_P5.08mm_Vertical
R10: 1K; R_Axial_DIN0207_L6.3mm_D2.5mm_P2.54mm_Vertical
RV1: 10D561K; RV_Disc_D7mm_W4.2mm_P5mm
U1: LD1117S33TR_SOT223; SOT-223-3_TabPin2
U2: 74LS14; DIP-14_W7.62mm_Socket_LongPads
dev_board1: Black_pill_stm32f411; Maple_Mini

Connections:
+3.3V: C9.1, J1.3, J5.1, R2.2, R3.2, U1.2 (VO)
+3.3Vmc: J4.2, J13.2, J14.2, J15.2, dev_board1.38 (3.3)
+5V: C1.1, C5.1, C8.1, D3.1 (K), J2.4, J3.2, K1.5, PS1.4 (+Vout), R7.2, R8.2, R9.2, R11.2, U1.3 (VI), U2.14 (VCC), dev_board1.40 (5V)
/Rx_mcu_esp01: J5.2, dev_board1.7 (A10)
/Tx_mcu_esp01: J5.3, dev_board1.6 (A9)
/fan: R3.1, U2.3, dev_board1.8 (A11)
/fire: R2.1, U2.5, dev_board1.5 (A8)
/zc: J1.2, dev_board1.9 (A12)
Bobina_ventilador: J7.1, K1.3
CS_0: J4.4, dev_board1.33 (A7)
CS_1: J13.4, dev_board1.34 (B0)
CS_2: J14.4, dev_board1.35 (B1)
CS_3: J15.4, dev_board1.36 (B2)
ENCODER_A: J12.3, R8.1, dev_board1.26 (A0)
ENCODER_B: J12.2, R9.1, dev_board1.27 (A1)
ENCODER_BTN: J12.1, R11.1, dev_board1.28 (A2)
GND: C1.2, C5.2, C8.2, C9.2, J1.4, J2.3, J3.1, J4.1, J5.4, J10.2, J12.4, J12.5, J13.1, J14.1, J15.1, OC1.3, PS1.3 (-Vout), Q1.1 (E), R1.1, U1.1 (GND), U2.7 (GND), dev_board1.19 (G), dev_board1.39 (G)
I2C1_SCL: J1.6, dev_board1.14 (B6)
I2C1_SDA: J1.5, dev_board1.15 (B7)
LINE: F1.1, F2.1, J6.2, J7.2
NEUT: C2.2, FL1.3, J6.1, J11.1, K1.1, R6.2, RV1.2
unnamed: C2.1, F1.2, FL1.1, RV1.1
unnamed: D1.2 (1), R6.1
unnamed: D1.4 (2), R5.1
unnamed: D1.1 (+), OC1.1
unnamed: D1.3 (-), OC1.2
unnamed: D3.2 (A), K1.2, Q1.3 (C)
unnamed: J2.1, J3.3
unnamed: J2.2, J3.4
unnamed: J10.1, U2.6
unnamed: F2.2, J11.2, R5.2
unnamed: OC1.4, R7.1, U2.1
unnamed: FL1.2, PS1.1 (AC/L)
unnamed: FL1.4, PS1.2 (AC/N)
unnamed: Q1.2 (B), R10.1
unnamed: R1.2, U2.9, U2.11, U2.13
unnamed: R10.2, U2.4
SPI1_MISO: J4.5, J13.5, J14.5, J15.5, dev_board1.32 (A6)
SPI1_SCK: J4.3, J13.3, J14.3, J15.3, dev_board1.31 (A5)
built_in_led: dev_board1.22 (C13)
zero: J2.5, U2.2

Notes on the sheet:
Alimentación
Interfaz de usuario pantalla touch y web
Ventaliación y extración de humos
resistence
Conecciones y montaje mecánico
Potencia
Control

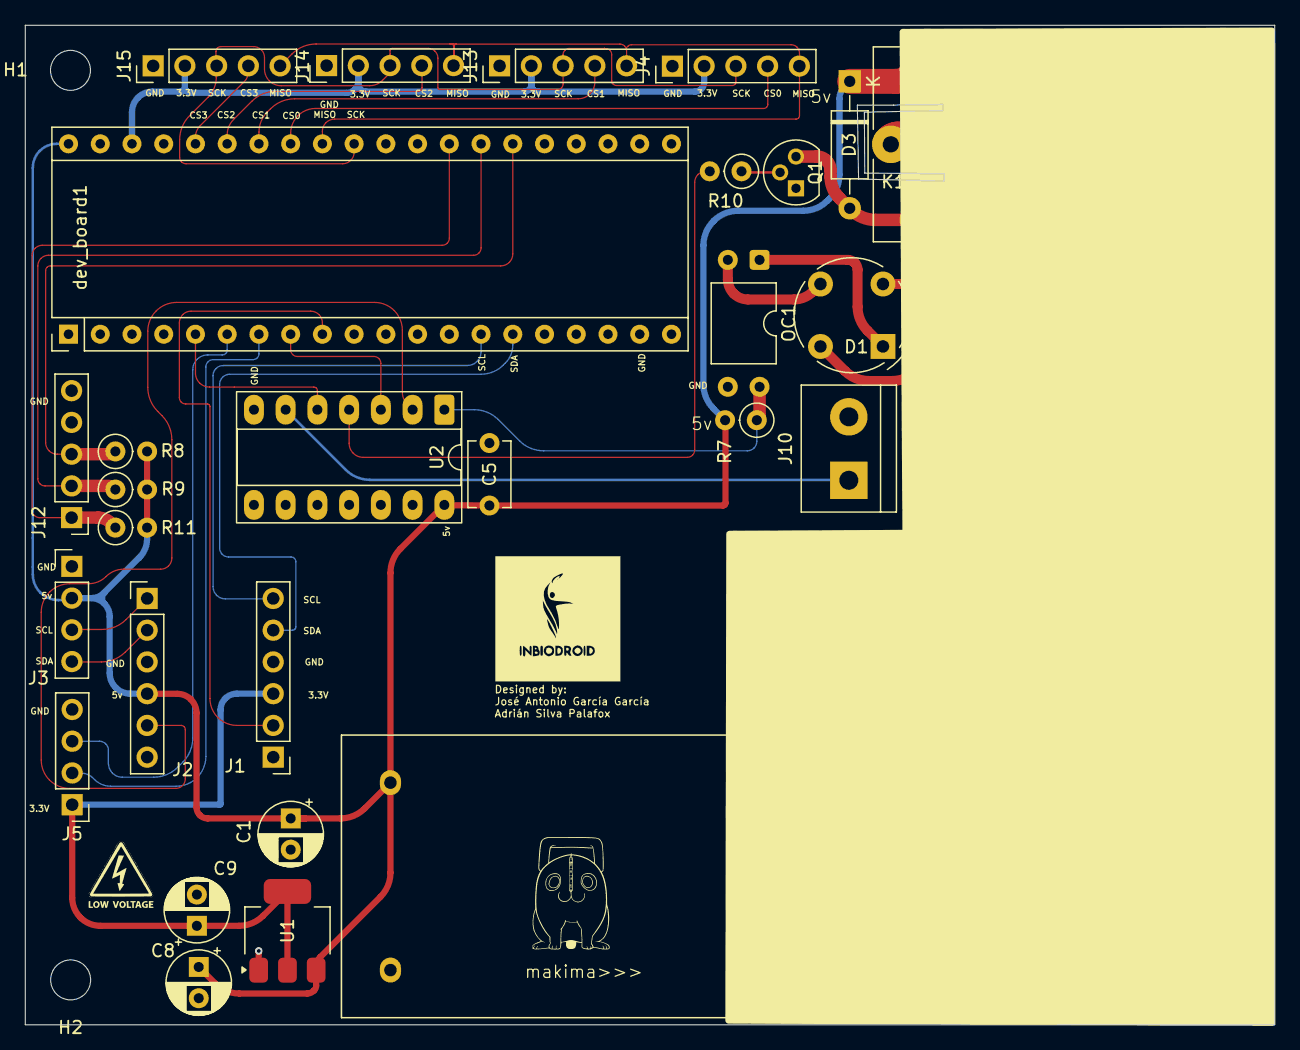
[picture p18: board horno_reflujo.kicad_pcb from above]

Board: 2 copper layers, 100.0 x 80.0 mm, 42 parts (0 on the bottom side), 39 nets.

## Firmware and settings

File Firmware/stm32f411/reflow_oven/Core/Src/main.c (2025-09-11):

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
/* Includes ------------------------------------------------------------------*/
#include "main.h"

/* USER CODE BEGIN Includes */
/******************
 * Project includes
 ******************/
// Standard libs
#include <stdlib.h>
#include <stdio.h>
#include <stdbool.h>
#include <string.h>

// GUI related
//#include "UI/screen/ssd1306.h"
#include "UI/gui_backend.h"

// Hardware and logic control libs
#include "sensors/max6675.h"
#include "sensors/digital_filter.h"
#include "logic_control/reflow_oven_process.h"
/* USER CODE END Includes */

/* USER CODE BEGIN PD */
// Comment all debug modes to work as a reflow-oven
#define DEBUG_RANDOM_CROSSOVER_ACTUATOR
//#define DEBUG_MANUAL_PID_TUNNING
//#define DEBUG_CALIBRATION_THERMOCOUPLE

// Select a suitable digital filter
#define EMA_FILTER
// #define MV_FILTER
#ifdef MV_FILTER
#define FILTER_WINDOW 3    //window size (number of samples) for Circular buffer
#endif

// TX-UART and RX-UART-DMA parameters
#define RX_BUFFER_SIZE 30	//characters
#define TX_BUFFER_SIZE 30	//characters
#define TIMEOUT_RX 3000 	//ms
/* USER CODE END PD */

I2C_HandleTypeDef hi2c1;
DMA_HandleTypeDef hdma_i2c1_tx;

SPI_HandleTypeDef hspi1;

TIM_HandleTypeDef htim1;
TIM_HandleTypeDef htim2;
TIM_HandleTypeDef htim3;

UART_HandleTypeDef huart1;
DMA_HandleTypeDef hdma_usart1_rx;
DMA_HandleTypeDef hdma_usart1_tx;

/* USER CODE BEGIN PV */

/**************************
 * PROJECT GLOBAL VARIABLES
 *************************/
// esp01 related
volatile uint8_t RXuart_size = 1;		// Size of data to handle DMA RX uart
char webserv_buf[TX_BUFFER_SIZE] = {0}; // Tx uart buffer
char RXbuffer[RX_BUFFER_SIZE] = {0};   	// RX uart buffer
volatile uint32_t lastTime_RX; 			// Last RX timestamp (ms)
volatile bool TXuart_flag = true; 		// True->send    False->No-send
volatile bool RXuart_flag = false; 		// True->receive False->No-receive

// PID controller related
PIDController PID;
volatile uint8_t timers_isr = 0; 		// PID's sampling timer state is reflected in BIT0

// Sensors
float chamber_temp = 0.0f;      			   		// Celcius
float tempReadings[MAX6675_MAX_DEVICES] = {0.0f};	// Stores each sensor's temperature
MAX6675_Driver_t tempSensors;				   		// Intance sensor's driver
// Sensors' filter
#ifdef MV_FILTER
MovingAverage filter;								// Moving average filter instance
float filterBuffer[FILTER_WINDOW]; 					// Circular buffer for digital filter
#elif defined(EMA_FILTER)
EMAFilter filter;									// Exponential moving average filter instance
#endif
/* USER CODE END PV */

void SystemClock_Config(void);
static void MX_GPIO_Init(void);
static void MX_DMA_Init(void);
static void MX_SPI1_Init(void);
static void MX_TIM1_Init(void);
static void MX_I2C1_Init(void);
static void MX_TIM2_Init(void);
static void MX_USART1_UART_Init(void);
static void MX_TIM3_Init(void);
/* USER CODE BEGIN PFP */

/*********************
 * PROTOTYPE FUNCTIONS
 *********************/
void put_webserver_data(void);
void get_webserver_data(void);
void chamber_sense_temperature(void);
void update_randomCrossover_actuator(uint8_t);
void fan_control(bool);

/* USER CODE END PFP */

/**
  * @brief  The application entry point.
  * @retval int
  */
int main(void)
{

  /* MCU Configuration--------------------------------------------------------*/

  /* Reset of all peripherals, Initializes the Flash interface and the Systick. */
  HAL_Init();

  /* Configure the system clock */
  SystemClock_Config();

  /* Initialize all configured peripherals */
  MX_GPIO_Init();
  MX_DMA_Init();
  MX_SPI1_Init();
  MX_TIM1_Init();
  MX_I2C1_Init();
  MX_TIM2_Init();
  MX_USART1_UART_Init();
  MX_TIM3_Init();
  /* USER CODE BEGIN 2 */

  /****************************************************
   * INITIALIZATION OF HARDWARE AND SOFTWARE COMPONETNS
   ****************************************************/

  // PID's parameters
  PID_Init(&PID,
           2.5f,    // kp
           0.05f, 	// ki
           0.075f,  // kd
           0.3f,    // tau		-> LowPass filter
           0.0f,    // limMIN
           120.0f,  // limMAX 	-> 120 cycles since AC mains are 60hz
           -50.0f, 	// limMinInt
           50.0f,  	// limMaxInt
           0.25f);  // tsample in seconds

  // Temperature sensors
  HAL_TIM_Base_Start_IT(&htim3); // Enable sampling timer ISR
#ifdef MV_FILTER
  moving_average_init(&filter, filterBuffer, FILTER_WINDOW);
#elif defined(EMA_FILTER)
  ema_init(&filter, 0.35f);
#endif
  MAX6675_Init(&tempSensors, &hspi1);
  for (int i=0; i<MAX6675_MAX_DEVICES; i++) MAX6675_AddDevice(&tempSensors, i);

  // Zero-Crossover and fan actuators
  HAL_TIM_PWM_Start(&htim1, TIM_CHANNEL_1);
  update_randomCrossover_actuator(0);	//off
  fan_control(false); 					//off

  // User's input via encoder
  encoder.prev_dir = 0;
  encoder.prev_cnt = 0;
  HAL_TIM_Encoder_Start(&htim2, TIM_CHANNEL_ALL);

  // GUI-SM-Oled-screen | ReflowOven-SM | ESP01
  GUI_Init();
  ReflowOven_Init();
  HAL_UART_Receive_DMA(&huart1, (uint8_t*)RXbuffer, RXuart_size);

  /* USER CODE END 2 */

  /* Infinite loop */
  /* USER CODE BEGIN WHILE */
  while (1)
  {
    /* USER CODE END WHILE */

    /* USER CODE BEGIN 3 */
		/****************************************************************
		*  Check bti0 for temperature sensing / PID feedback-input update
		*  1.- Get temperature inside oven
		*  2.- Process data and update state
		*  3.- Act on heat elements
		*****************************************************************/
	if (timers_isr & 0x01) {
		timers_isr &= ~0x01;
		chamber_sense_temperature();
#ifdef DEBUG_RANDOM_CROSSOVER_ACTUATOR
		PID.out = PID.Kp;
		update_randomCrossover_actuator((uint8_t)PID.out); 			// PID.out <= 120 to test heating elements
#elif defined(DEBUG_MANUAL_PID_TUNNING)
	    PID_Update(&PID, 100.0f, chamber_temp); 					// SoakTime variable is used as set-point
		update_randomCrossover_actuator((uint8_t)PID.out);
#else	// Work as an actual reflow-oven
		ReflowOven_operate(&PID, chamber_temp, HAL_GetTick());
		update_randomCrossover_actuator((uint8_t)PID.out);
#endif
		put_webserver_data(); 										// Update ESP01 webserver
    }
    else {
    	/*****************************************
    	 * Receive user's inputs via
    	 * esp01 web server and encoder-OledScreen
		 *****************************************/
		get_webserver_data();
		Encoder_EventUpdate(&encoder);

		/**********************
		* Process user's inputs
		***********************/
		GUI_Process();

		/********************
		* Oled screen update
		********************/

		/***********************************
		* Handle OVEN-SM with GUI-SM states
		***********************************/
		if (ReflowOven.emergencyStop) gui_sm.is_process_running = false;
		if(!gui_sm.is_process_running){
		  ReflowOven_stopProcess();
		  fan_control(false);
		}else{
		  ReflowOven_startProcess();
		  fan_control(true);
		}
    }
  }
  /* USER CODE END 3 */
}

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
/* USER CODE BEGIN 4 */
/*************************
 * PROTORYPES' DEFINITIONS
 *************************/
/**
 * @brief Updates PWM duty cycle for AC heating elements
 * @param ON_semiCicles Number of semi-cycles to turn on heating elements
 */
void update_randomCrossover_actuator(uint8_t ON_semiCicles){
    __HAL_TIM_SET_COMPARE(&htim1, TIM_CHANNEL_1, ON_semiCicles);
}

/**
 * @brief Controls fan relay state
 * @param state true = fan ON, false = fan OFF
 * @note Uses inverted logic due to NOT gate in hardware
 */
void fan_control(bool state){
    HAL_GPIO_WritePin(fan_relay_GPIO_Port, fan_relay_Pin, !state);
    HAL_GPIO_WritePin(built_in_led_GPIO_Port, built_in_led_Pin, !state);
}

/**
 * @brief Reads temperature from MAX6675_MAX_DEVICES sensors and calculates chamber average temperature
 * @note Updates global variable chamber_temp with averaged result
 */
void chamber_sense_temperature(void)
{
	float sum = 0.0f;
    uint8_t valid_sensor_count = 0;

    for (int sensor = 0; sensor < MAX6675_MAX_DEVICES; sensor++) {
    	if (MAX6675_ReadTemperature(&tempSensors, sensor) != HAL_OK) continue;
    	if (MAX6675_GetTemperature(&tempSensors, sensor, tempReadings + sensor) != HAL_OK) continue;
		sum += tempReadings[sensor];
		valid_sensor_count++;
    }

    if (valid_sensor_count) {
    	chamber_temp = (sum / valid_sensor_count); 						// Compensate for sensor

#ifdef MV_FILTER
    	chamber_temp = moving_average_update(&filter, chamber_temp);	// Digital filter
#elif defined(EMA_FILTER)
    	chamber_temp = ema_process(&filter, chamber_temp);
#endif
	}
    else {
	    chamber_temp = MAX6675_INVALID_TEMP;
	}
}

/**
 * @brief Formats float data with wrapper characters and transmits via UART DMA
 */
void put_webserver_data(void){
	if (TXuart_flag) {
    	TXuart_flag = false;
#ifdef DEBUG_CALIBRATION_THERMOCOUPLE
    	snprintf(webserv_buf, sizeof(webserv_buf),"M%.2fN%.2fP%dE%d\r\n", tempReadings[0], tempReadings[1], (uint8_t)PID.out, (uint8_t)ReflowOven_getCurrentPhase());
#else
    	snprintf(webserv_buf, sizeof(webserv_buf),"t%.2fP%dE%d\r\n", chamber_temp, (uint8_t)PID.out, (uint8_t)ReflowOven_getCurrentPhase());
#endif
    	HAL_UART_Transmit_DMA(&huart1,(uint8_t*)webserv_buf,strlen(webserv_buf));
	}
}

/**
 * @brief  Parses UART data received from the webserver and applies configuration changes.
 *
 * This function is called periodically to check if new data has been received via
 * UART (in this case from an ESP01 acting as a webserver). It parses a single-character
 * command followed by a float value, and updates either the PID controller or the
 * Reflow Oven process accordingly.
 *
 * @note The function is triggered only when a full valid message has been received (flag + size check).
 *       The function resets the RX flag upon successful parsing.
 */
void get_webserver_data(void){

	// Check if new data has been received via UART
    if (RXuart_flag && RXuart_size==1) {
        // Reset RX flag upon successful parsing
        RXuart_flag = false;

        // Parse single-character command followed by a float value
        switch (RXbuffer [0]) {
            // PID controller variables
            case 'p':  // Update PID Kp (proportional) parameter
                PID_UpdateKp(&PID, strtof(RXbuffer + 1, NULL));
                break;
            case 'i':  // Update PID Ki (integral) parameter
                PID_UpdateKi(&PID, strtof(RXbuffer + 1, NULL));
                break;
            case 'd':  // Update PID Kd (derivative) parameter
                PID_UpdateKd(&PID, strtof(RXbuffer + 1, NULL));
                break;

            // Reflow oven controller variables
            case 'a':  // Update pre-heat up rate
                ReflowOven_modifyParameters(PARAM_Pre_HeatUpRate, strtof(RXbuffer + 1, NULL));
                break;
            case 'b':  // Update soak temperature
                ReflowOven_modifyParameters(PARAM_SoakTempeture, strtof(RXbuffer + 1, NULL));
                break;
            case 'c':  // Update soak time
                ReflowOven_modifyParameters(PARAM_SoakTime, strtof(RXbuffer + 1, NULL));
                break;
            case 'D':  // Update heat-up rate
                ReflowOven_modifyParameters(PARAM_HeatUpRate, strtof(RXbuffer + 1, NULL));
                break;
            case 'e':  // Update reflow temperature
                ReflowOven_modifyParameters(PARAM_ReflowTempeture, strtof(RXbuffer + 1, NULL));
                break;
            case 'f':  // Update reflow time
                ReflowOven_modifyParameters(PARAM_ReflowTime, strtof(RXbuffer + 1, NULL));
                break;
            case 'g':  // Update cool-down rate
                ReflowOven_modifyParameters(PARAM_CoolDownRate, strtof(RXbuffer + 1, NULL));
                break;
            case 'h':  // Update cool-down temperature
                ReflowOven_modifyParameters(PARAM_CoolDownTempeture, strtof(RXbuffer + 1, NULL));
                break;

            // Oven's control button
            case 'B':  // Start or stop reflow oven process
                if(RXbuffer [1] - '0') { // We do math with ASSCI code
                    gui_sm.is_process_running  = true;
                } else {
                    gui_sm.is_process_running  = false;
                }
                break;
        }
    }

    if (HAL_DMA_GetState(&hdma_usart1_rx)==HAL_DMA_STATE_READY ||    // Handle a DMA abort caused by ESP01 boot message
       (RXuart_flag && (HAL_GetTick() - lastTime_RX > TIMEOUT_RX) )) // Timeout (3s) of waiting in Rx for full message
    {
        RXuart_flag = false;
        HAL_UART_DMAStop(&huart1);
        HAL_UART_Receive_DMA(&huart1, (uint8_t*)RXbuffer, 1);
        return;
    }
}

/************
* CALLBACKS
***********/
/**
 * @brief Callback invoked when UART reception via DMA is complete.
 *
 * This function handles a two-stage UART reception using DMA:
 * 1. In the first stage, it receives a single byte which indicates the size of the upcoming message.
 * 2. In the second stage, it sets up DMA to receive the full message of that specified size.
 *
 * When the full message is received:
 * - It null-terminates the buffer for safe parsing.
 * - It sets a flag to indicate new data is available.
 *
 * @note This callback reinitializes DMA reception every time it is called,
 *       enabling continuous, non-blocking UART communication.
 *
 * @param huart Pointer to a UART_HandleTypeDef structure with the UART instance.
 */
void HAL_UART_RxCpltCallback(UART_HandleTypeDef *huart) {
	if (RXuart_flag) {
		// Full message received
		RXuart_size = 1; // Reset to expect size byte next, also works as a flag in get_webserver_data()
		HAL_UART_Receive_DMA(&huart1, (uint8_t*)RXbuffer, RXuart_size);
	} else {
		// First byte received, it tells us the upcoming message size
		RXuart_size = (uint8_t)RXbuffer[0];
		HAL_UART_Receive_DMA(&huart1, (uint8_t*)RXbuffer, RXuart_size);
		RXuart_flag = true;
		lastTime_RX = HAL_GetTick();
	}
}

/**
 * @brief Callback invoked when UART transmission via DMA is complete.
 *
 * @note Ensure that NVIC interrupts for UART are enabled, otherwise
 *       this callback won't be triggered.
 */
void HAL_UART_TxCpltCallback(UART_HandleTypeDef *huart){
	if (huart == &huart1){
		TXuart_flag = true; // Enables STATE_MACHINE_UDP_SEND
	}
}

/**
 * @brief GPIO external interrupt callback
 * @param GPIO_Pin Pin that triggered the interrupt
 */
void HAL_GPIO_EXTI_Callback(uint16_t GPIO_Pin)
{
    if (GPIO_Pin == encoder_pulse_Pin)
    {
        // TODO: Add a anti-bouncing algorithm
        encoder.isr_reg |= 0x01;
    }
}

/**
 * @brief Timer period elapsed callback
 * @param htim Timer handle that triggered the callback
 */
void HAL_TIM_PeriodElapsedCallback(TIM_HandleTypeDef *htim)
{
    // ISR for periodic sample of sensors
    if (htim == &htim3)
    {
        timers_isr |= 0x01;
    }
}

/* USER CODE END 4 */
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


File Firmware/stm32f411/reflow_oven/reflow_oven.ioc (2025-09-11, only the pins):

Mcu.UserName=STM32F411CEUx
PA0-WKUP.GPIO_Label=encoder_A
PA0-WKUP.Signal=S_TIM2_CH1_ETR
PA1.GPIO_Label=encoder_B
PA1.Signal=S_TIM2_CH2
PA10.Signal=USART1_RX
PA11.GPIO_Label=fan_relay
PA11.Signal=GPIO_Output
PA12.GPIO_Label=zc_crossing
PA12.Signal=S_TIM1_ETR
PA13.Signal=SYS_JTMS-SWDIO
PA14.Signal=SYS_JTCK-SWCLK
PA2.GPIO_Label=encoder_pulse
PA2.Signal=GPXTI2
PA5.Signal=SPI1_SCK
PA6.Signal=SPI1_MISO
PA7.GPIO_Label=CS_0
PA7.Signal=GPIO_Output
PA8.GPIO_Label=fire
PA8.Signal=S_TIM1_CH1
PA9.Signal=USART1_TX
PB0.GPIO_Label=CS_3
PB0.Signal=GPIO_Output
PB1.GPIO_Label=CS_2
PB1.Signal=GPIO_Output
PB2.GPIO_Label=CS_1
PB2.Signal=GPIO_Output
PB6.Signal=I2C1_SCL
PB7.Signal=I2C1_SDA
PC13-ANTI_TAMP.GPIO_Label=built_in_led
PC13-ANTI_TAMP.Signal=GPIO_Output
PC14-OSC32_IN.Signal=RCC_OSC32_IN
PC15-OSC32_OUT.Signal=RCC_OSC32_OUT

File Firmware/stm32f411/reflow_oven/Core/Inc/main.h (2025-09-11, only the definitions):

#define built_in_led_Pin GPIO_PIN_13
#define built_in_led_GPIO_Port GPIOC
#define encoder_A_Pin GPIO_PIN_0
#define encoder_A_GPIO_Port GPIOA
#define encoder_B_Pin GPIO_PIN_1
#define encoder_B_GPIO_Port GPIOA
#define encoder_pulse_Pin GPIO_PIN_2
#define encoder_pulse_GPIO_Port GPIOA
#define encoder_pulse_EXTI_IRQn EXTI2_IRQn
#define CS_0_Pin GPIO_PIN_7
#define CS_0_GPIO_Port GPIOA
#define CS_3_Pin GPIO_PIN_0
#define CS_3_GPIO_Port GPIOB
#define CS_2_Pin GPIO_PIN_1
#define CS_2_GPIO_Port GPIOB
#define CS_1_Pin GPIO_PIN_2
#define CS_1_GPIO_Port GPIOB
#define fire_Pin GPIO_PIN_8
#define fire_GPIO_Port GPIOA
#define fan_relay_Pin GPIO_PIN_11
#define fan_relay_GPIO_Port GPIOA
#define zc_crossing_Pin GPIO_PIN_12
#define zc_crossing_GPIO_Port GPIOA

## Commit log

2025-04-23 Estado limpio del proyecto
    [Cotizacion_mercadolibre.xlsx, cotizacion_unit.xlsx, cotizacion_welectronics.xlsx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]
2025-04-23 deleted: Presupuestos_materiales/compras/.~lock.Cotizacion_mercadolibre.xlsx# deleted: Presupuestos_materiales/compras/.~lock.cotizacion_welectronics.xlsx# deleted: Presupuestos_materiales/compras/Co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
    [Cotizacion_mercadolibre.xlsx, cotizacion_unit.xlsx, cotizacion_welectronics.xlsx]
2025-04-25 modified: Firmware/reflow_oven/.settings/language.settings.xml modified: Firmware/reflow_oven/Core/Inc/gui_backend.h modified: Firmware/reflow_oven/Core/Inc/main.h modified: Firmware/reflow_oven/Core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
2025-04-25 timersconfig reflowoven_logic
2025-04-25 timersconfig reflowoven_logic2
2025-05-16 pcb updated :)
    [horno_reflujo.kicad_pcb, horno_reflujo.kicad_sch]
2025-05-30 actualización del main
    [horno_reflujo-B_Cu.gbr, horno_reflujo-B_Mask.gbr, horno_reflujo-B_Paste.gbr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]
2025-05-31 actualizacion al main
    [horno_reflujo.kicad_pcb]
2025-05-31 adrian revision pcb
    [horno_reflujo.kicad_pcb]
2025-05-31 adrian revision pcb2
2025-06-01 mounting holes update
    [designators.csv, horno_reflujo.kicad_pcb, horno_reflujo.kicad_sch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]
2025-06-01 mcu pin update
    [horno_reflujo.kicad_pcb]
2025-06-01 trash files deleted
    [horno_reflujo-B_Cu.gbr, horno_reflujo-B_Mask.gbr, horno_reflujo-B_Paste.gbr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]
2025-06-02 Update pcb
    [bom.csv, designators.csv, horno_reflujo.kicad_pcb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]
2025-07-08 74ls04 inputs are now grounded
    [horno_reflujo.kicad_sch]
2025-07-08 74ls04 inputs now have pull-up/down resistors
    [horno_reflujo.kicad_sch]
2025-09-11 Documentation v1 functional demo (esp01)
    [regresion_horno.xlsx, regresion_horno2.xlsx]
2025-09-11 Documentation v1 functional demo (stm32f411)
2025-09-11 Documentation v1 functional demo (Hardware)
    [bom.csv, designators.csv, esquema_horno_no_modificado.kicad_sch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]
2025-09-11 Documentation v1 functional demo
    [bom.csv, designators.csv, esquema_horno_no_modificado.kicad_sch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]

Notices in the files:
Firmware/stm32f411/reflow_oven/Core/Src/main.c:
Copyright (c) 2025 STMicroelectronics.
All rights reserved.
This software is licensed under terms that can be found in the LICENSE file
